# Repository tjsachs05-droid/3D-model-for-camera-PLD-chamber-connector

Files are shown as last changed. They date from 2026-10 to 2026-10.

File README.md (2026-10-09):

# 3D model for camera PLD chamber connector

Parametric Blender models of mounts that hold a camera on a PLD chamber viewport. Both scripts require Blender 5.2.

In both, every part is revolved around the global X axis, with the camera on the left (X = 0) and the PLD chamber on the right. All dimensions are parameters at the top of each script. Every script has these options:
- `SCALE` resizes the whole model.
- Each part has its own matte color parameter.
- `CUTAWAY = True` shows a section view.
- `EXPLODE` pulls the parts apart.

To run a script, open it in the Scripting workspace and choose **Text > Run Script**, or run:

```
blender --python <script>.py
```

## Chamber connector: `pld_camera_connector.py`
This is the design being taken forward for 3D printing. Parameters are in inches. The model is built in millimetres, so exported files come out the right size for slicers, and Blender displays lengths in inches.

- **CameraMount**: a bottom half-cylinder cradle for the camera, joined to a full tube that slides into the adapter. A lip at its chamber end keeps it from pulling out.
- **CameraCover**: a top half-cylinder that covers the camera. Its tongue slides into a groove in the CameraMount tube.
- **ChamberAdapter**: grips the mount tube with set screws in its collar, then flares out to a face that sits on the viewport flange. An indent in that face fits around the protruding glass. Three prongs reach over the flange's side, each with a set screw that clamps onto it.
- **ChamberAdapter2**: the same adapter, set up for the alternate 6" viewport and placed below the assembly. It has its own `ADAPTER2_*` parameters. `ADAPTER2_GAP` sets the space between it and the assembly.

Every screw hole is sized to tap for 5/16"-24. Each one sits in a raised round pad (`SCREW_PAD_DIAMETER`, `SCREW_PAD_THICKNESS`), so there's more plastic for the threads. The pad's sides slope at 45° down to the wall, so no part of it hangs flat when printed. The mount tube also gets a band (`JOINT_PAD_THICKNESS`) where the cover's tongue slides in, so the walls on either side of the groove aren't too thin.

The defaults fit an Ender-3 V2 (220 × 220 × 250 mm) with each part printed standing on end. The adapter is 9.75" tall including the prongs, and the mount is 9.75" long. `PRINTER_MAX_HEIGHT` and `PRINTER_BED_SIZE` make the script stop with an error if a part grows too big. Set them to `None` to skip the check.

The main dimensions are in their own section at the top of the script:
- `CAMERA_DIAMETER` (1.6") is the camera's neck. The mount grips it for `NECK_BORE_LENGTH` (3/4"). The bore then widens to the focus dial through a shoulder at `NECK_TAPER_ANGLE` (75° from the axis). The cover stops `COVER_SETBACK` (1/2") short of the camera end, so it grips the neck for only 1/4".
- `FOCUS_DIAL_DIAMETER` (2 1/8") is the camera's focus dial.
- `VIEWPORT_DIAMETER` (8") is the raised viewport flange.
- `THICKNESS` (1/8") is the wall thickness of every part, including the prongs.

The glass is set by `GLASS_DIAMETER` and `RECESS_DEPTH`. `INSERTION_DEPTH` sets how far the mount sits in the adapter, which sets the camera-to-viewport distance. `section_preview.png` is a cutaway render.

### Printing
Each run of the script writes one STL per part to `stl/`: `CameraMount.stl`, `CameraCover.stl` and `ChamberAdapter.stl`. `EXPORT_FOLDER` and `EXPORT_PARTS` control this. Add `"ChamberAdapter2"` to `EXPORT_PARTS` to get the 6" adapter too.

The files are always whole parts, even when `CUTAWAY` is on. They're in millimetres, watertight, and already standing the way they should print:
- **CameraMount** stands on its lip end, which is a full ring on the bed, so the cover's groove opens upward. There are two overhangs. The 1/16" edge of the joint band prints fine. The 75° neck shoulder near the top is almost flat when printed, so it may sag a little. Add support there if the focus dial needs to seat cleanly against it, or set `NECK_TAPER_ANGLE` to 45 to print it without support.
- **CameraCover** stands on its camera end and needs no supports.
- **ChamberAdapter** stands on its small (collar) end, so the flange face prints last as a clean top surface. Behind the face, the inside slopes at 45° down to the cone, so the part needs no supports. Keep `CONE_ANGLE` at 45 or less for the same reason. A brim helps the narrow base stay stuck to the bed.

Print with at least 4 walls (perimeters) so the plastic around the screw holes is solid. Then drill the holes out with a letter-I (0.272") bit and cut the threads with a 5/16"-24 tap.

## Model telescope: `model_telescope.py`
An earlier telescoping design that isn't being taken forward. Its parameters are in mm. Each tube has an inward lip at its camera end that catches the outward foot of the tube inside it.
- **Telescope Mount** (1): a camera cradle and tube with an outward foot at its chamber end.
- **Telescope Cover** (1.5): a half-cylinder cover with the same tongue-and-groove joint as the connector.
- **Telescope Segment N** (2): middle tubes, repeated `SEGMENT_COUNT` times. Each one is sized from the part inside it, so they nest.
- **Telescope Base** (3): the outermost tube, which sits against the chamber.

`EXTENSION` sets how far the telescope is extended, from 0 (collapsed) to 1 (fully extended). `telescope_preview.png` is a cutaway render.

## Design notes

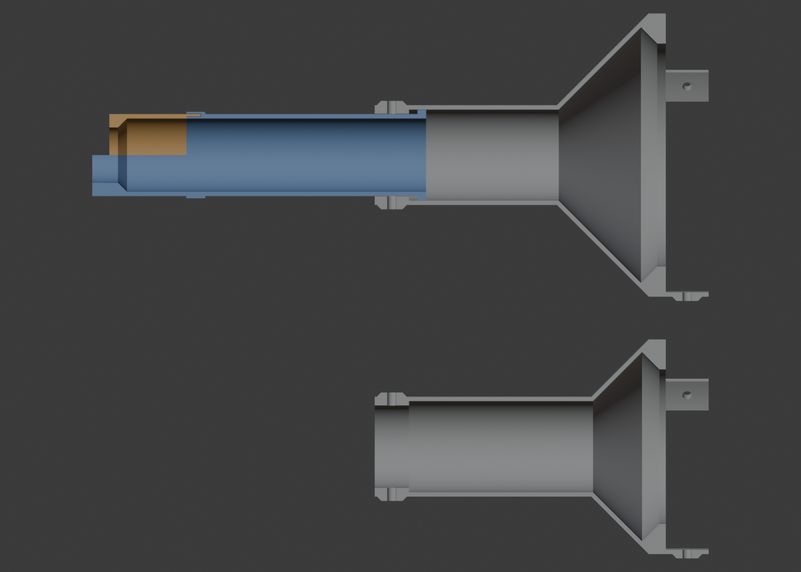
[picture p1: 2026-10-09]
section_preview.png

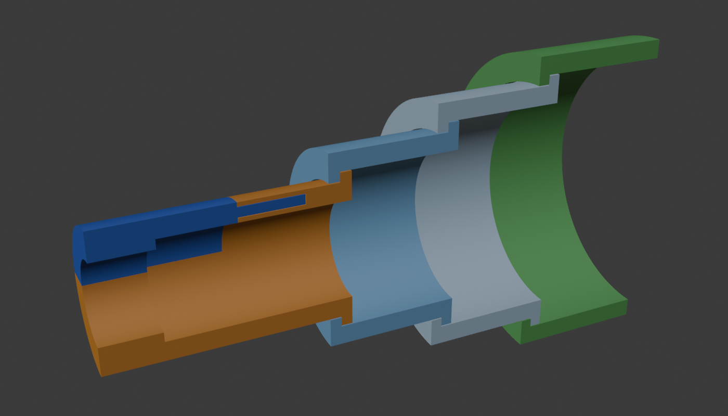
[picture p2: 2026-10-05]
telescope_preview.png

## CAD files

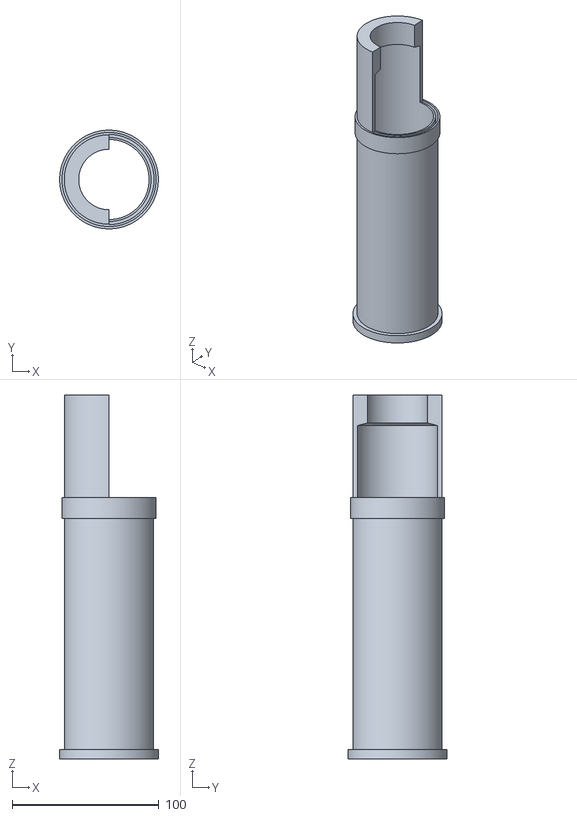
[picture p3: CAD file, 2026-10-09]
stl/CameraMount.stl
67.2 x 67.2 x 247.6

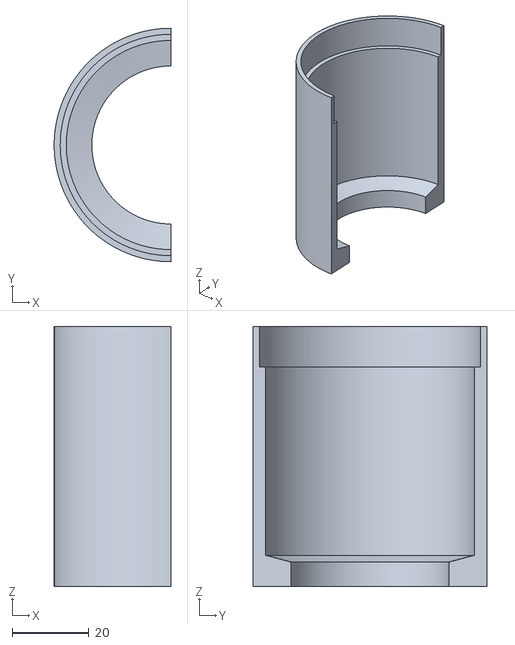
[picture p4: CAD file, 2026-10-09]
stl/CameraCover.stl
30.4 x 60.8 x 67.7

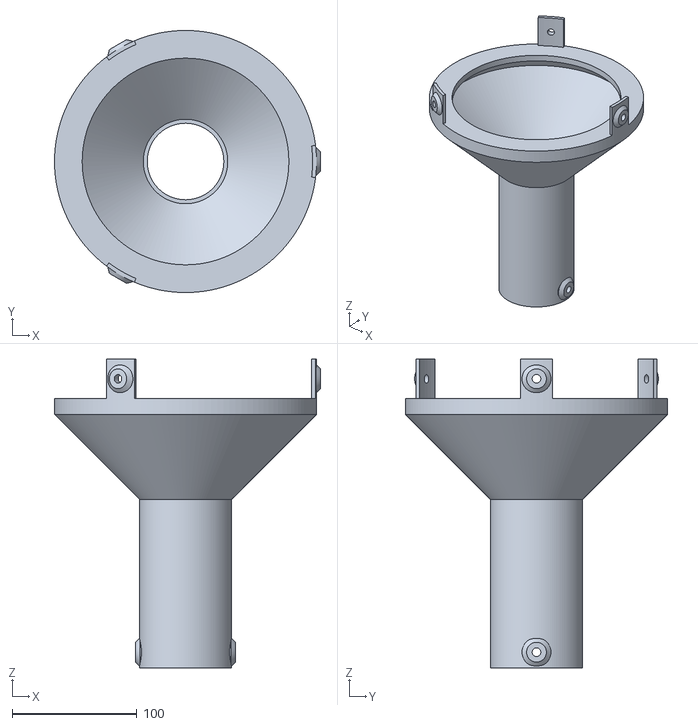
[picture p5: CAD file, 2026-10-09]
stl/ChamberAdapter.stl
213.2 x 210.1 x 247.6

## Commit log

2026-10-05 Add parametric Blender script for camera PLD chamber connector
    Builds the ChamberAdapter, CameraMount and CameraCover around the X axis,
    with all sketch dimensions (x1-x9, theta1, theta2) as parameters.
2026-10-05 Add per-part colors, a SCALE factor, and new default dimensions
    Each part gets its own matte material (ADAPTER_COLOR, MOUNT_COLOR,
    COVER_COLOR). SCALE resizes the whole finished model. Defaults updated
    to the new dimension values, and CUTAWAY is now on by default.
2026-10-05 Fix cutaway leaving holes in the CameraMount and CameraCover
    Points at 90/180/270 degrees came out of cos/sin a hair off the split
    and cutaway planes, so the exact boolean left the section faces broken.
    Snap them to exact zeros.
2026-10-05 Fix cutaway missing parts of the ChamberAdapter at larger SCALE
    The cutaway box was a fixed 10 m, so a scaled-up adapter stuck out past
    it. Size the box from each part instead, reading the mesh vertices since
    bound_box/matrix_world are stale right after scaling. Also zero out float
    noise after every mesh build and boolean so the section faces stay closed.
2026-10-05 Add parametric model telescope script
    Five-part telescoping camera mount: mount, half-cylinder cover, two
    middle segments that nest by size, and a base against the chamber. All
    distances, SCALE, EXTENSION and per-part colors are parameters.
2026-10-06 Add ChamberAdapter2, a separately adjustable adapter below the assembly
    Adapter geometry now comes from adapter_geometry(prefix), so the main
    adapter reads X1, X2, ... and the new one reads ADAPTER2_X1, ADAPTER2_X2,
    ... with the same defaults. ADAPTER2_GAP and ADAPTER2_COLOR set its
    spacing and color.
2026-10-06 Rename connector parameters; lead with camera, viewport and thickness
    The sketch-label names (X1-X9, THETA1/2) become descriptive names, and
    CAMERA_DIAMETER, VIEWPORT_DIAMETER and THICKNESS now drive the model
    from their own section. The cone slant length (old X6) is derived from
    VIEWPORT_DIAMETER. Defaults reproduce the previous model.
2026-10-06 Describe the connector's main dimensions in the README
2026-10-06 Redesign connector for 3D printing: inches, glass indent, clamp prongs
    Parameters are now in inches (built in mm for STL export) with real
    camera and viewport sizes. The adapter's skirt is replaced by a face
    that sits on the viewport flange, an indent around the protruding glass,
    and three 1" prongs with 5/16"-24 set screws that clamp the flange.
    The camera bore steps from 1.6" to 2" with no taper, and walls are a
    uniform 3/16". ChamberAdapter2 is set up for the alternate 6" viewport.
2026-10-08 Fit the Ender-3 V2, thin walls to 1/8", pad screw holes and cover joint
    ADAPTER_LENGTH 8.5" and MOUNT_LENGTH 9.75" keep every part under the
    Ender-3 V2's 250 mm height. THICKNESS drops to 1/8". Each screw hole now
    sits in a raised round pad, and the mount tube gets a band around the
    tongue-and-groove joint so its walls stay printable. New PRINTER_MAX_HEIGHT
    and PRINTER_BED_SIZE checks stop the build if a part won't fit.
2026-10-08 Export one print-ready STL per part
    Each run writes stl/CameraMount.stl, CameraCover.stl and ChamberAdapter.stl:
    whole parts (never cut away), in mm, watertight, and stood on end the way
    they should print. EXPORT_FOLDER and EXPORT_PARTS control it, and the
    folder is found next to the script even when run from Blender's text editor.
    [CameraCover.stl, CameraMount.stl, ChamberAdapter.stl]
2026-10-08 Print the camera mount standing on its lip end
    The lip end is a full 2.5" ring on the bed (1.8 in2 vs 1.0 in2 for the
    half-ring camera end), and the cover's groove then opens upward instead
    of needing a bridge.
    [CameraMount.stl]
2026-10-08 Print the adapter small end down with no supports
    Behind the flange face, the inside now slopes at 45 degrees from the
    indent's edge out to the cone instead of a flat 3/4" ledge, so the
    adapter prints standing on its collar without supports. The flange face
    prints last as a clean top surface. Overhang needing support drops from
    21.6 in2 (prongs down) to 0.7 in2 (just the round screw pads).
    [ChamberAdapter.stl]
2026-10-08 Shorten the cover's tongue to a third (1.25" -> 5/12")
    The groove and the joint band on the mount shorten with it, and the
    cover now prints 3.17" tall instead of 4".
    [CameraCover.stl, CameraMount.stl]
2026-10-09 Bigger focus dial, shorter neck grip with 45 degree slope, set-back cover, 45 degree screw pads
    - FOCUS_DIAL_DIAMETER 2" -> 2 1/8" (both adapters fit the larger mount tube).
    - The mount grips the camera neck for 3/4", then the bore widens at 45
    degrees instead of a flat step, so it prints without a hanging ledge.
    - The cover follows the same bore but starts COVER_SETBACK (1/2") in, so
    it grips the neck for only 1/4".
    - Screw pads are now 45 degree cones on a buried post (5/8" flat face),
    so none of them hangs flat when printed.
    [CameraCover.stl, CameraMount.stl, ChamberAdapter.stl]
2026-10-09 Add NECK_TAPER_ANGLE for the neck-to-focus-dial shoulder (default 75 degrees)
    Measured from the axis like CONE_ANGLE; 90 gives a flat step. Used by
    both the mount and the cover.
    [CameraCover.stl, CameraMount.stl]
2026-10-12 Update focus dial and neck dimensions in connector
2026-10-12 Open the adapter collar for the joint band and use three collar screws
    The mount slides in through the collar, so its bore now clears the
    mount's joint band: JOINT_PAD_THICKNESS more on the radius plus the fit
    clearance. The mount's lip still catches on the collar by 0.0525".
    Three collar set screws at 270, 30 and 150 degrees line up with the
    prongs and centre the tube. Same for ChamberAdapter2. STLs regenerated,
    including the focus dial, neck and cover changes from ff2a0cd.
2026-10-12 Add optional push-in pegs as an alternative to the set screws
    One peg per collar and prong screw hole, exported together as Pegs.stl,
    standing on their knobs. Shanks are the hole size (PEG_CLEARANCE = 0)
    for a push fit, reach PEG_PRESS past the tube or flange, and have a
    bevelled tip; a 1/2" knob gives something to pull them out by.
